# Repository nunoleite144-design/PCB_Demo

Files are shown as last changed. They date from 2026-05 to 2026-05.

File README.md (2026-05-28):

# PCB do Painel Solar 1U — ICARUS

Repositório de trabalho relativo ao desenho preliminar da PCB do painel solar 1U do projeto ICARUS, no âmbito da Porto Space Team.

Esta versão agrega o projeto KiCad, os footprints preliminares e a documentação técnica de apoio à revisão interna.

## Revisão atual

A revisão de trabalho actual é a **v0.7**:

- `hardware/ICARUS_1U_Solar_Panel_PCB_v0p7.kicad_sch`
- `hardware/ICARUS_1U_Solar_Panel_PCB_v0p7.kicad_pcb`
- `hardware/ICARUS_1U_Solar_Panel_PCB_v0p7.kicad_pro`

Esta revisão adopta **1S2P (duas células em paralelo)** como topologia base, **move o conector Molex `J1` para a face inferior (`B.Cu`)** conforme orientação do líder de equipa, mantém os test pads `PANEL_NEG` e `PANEL_POS`, e mantém `BENCH_ONLY_PANEL_NEG`/`BENCH_ONLY_PANEL_POS` apenas como fallback de bancada. O `D1` (TVS DNP) e o `TP2` (SERIES_MID) da v0.6 foram **removidos** porque deixam de ser necessários em paralelo.

Estado desta revisão: **pré-validação física**. Não está aprovada para fabrico final nem para voo.

A v0.6 (2S1P série) permanece em histórico Git como branch `v0.6-internal-review` e em `main` antes do merge da v0.7.

## Estado atual

A configuração elétrica de referência é **1S2P** com duas células solares **TJ3xSCA-4080 Tipo 32** por painel, ligadas em paralelo.

Parâmetros de referência usados no dimensionamento:

| Parâmetro | Valor |
|---|---:|
| `Voc_cell` | 2.70 V @ 25 °C |
| `Vmp_cell` | 2.37 V @ 25 °C |
| `Jm` | 17.9 mA/cm² |
| Área ativa | 30.18 cm² |
| `dVoc/dT` | −6.0 mV/°C por célula |

Valores calculados para o painel 1S2P:

| Grandeza | Valor |
|---|---:|
| `Voc_panel` @ 25 °C BOL | 2.70 V |
| `Vmp_panel` @ 25 °C | 2.37 V |
| `Isc` @ 25 °C | ≈ 1.12 A |
| `Imp` @ 25 °C | ≈ 1.08 A |
| `Pmp` @ 25 °C | ≈ 2.65 W |

Ligação elétrica final (1S2P):

| Nó | Ligação |
|---|---|
| `SC1_NEG` (tabs/frente) | `PANEL_NEG` |
| `SC1_POS` (centro/verso) | `PANEL_POS` |
| `SC2_NEG` (tabs/frente) | `PANEL_NEG` |
| `SC2_POS` (centro/verso) | `PANEL_POS` |

Não existe net intermédia (`SERIES_MID` foi removida na transição 2S1P → 1S2P).

## Interface EPS I

O EPS usado é o **EnduroSat EPS I**. O pinout solar que deve ser respeitado no cabo/PCB é (Tabela 8 do EPS I User Manual):

| Pino do conector solar EPS I | Função |
|---:|---|
| 1 | PV− / negativo |
| 2 | PV− / negativo |
| 3 | PV+ / positivo |
| 4 | PV+ / positivo |

`J1` está montado em `B.Cu` (parte inferior da PCB) por instrução do líder de equipa, mantendo o pinout acima.

Limites relevantes por canal solar (Tabela 12 do EPS I User Manual):

| Limite | Valor | Notas |
|---|---:|---|
| Tensão mínima de entrada (boost UVLO) | ≈ 0.78 V | `VF_blocking_diode + 0.5 V` |
| Tensão típica de operação | 4.66 V | Ponto referenciado pelo EPS |
| Tensão máxima — OVP trigger | 5.5 V | EPS tem OVP **integrada** acima deste valor |
| Corrente máxima de entrada | 1.8 A | — |

A PCB e o harness devem ser verificados por continuidade antes de qualquer ligação ao EPS.

## Margens eléctricas (1S2P)

A transição para paralelo **elimina** o risco de sobretensão a frio que dominava a v0.6:

| Cenário | Valor 1S2P | vs limite 5.5 V (OVP trigger) |
|---|---:|---|
| `Voc_panel` @ 25 °C BOL | 2.70 V | margem 2.80 V |
| `Voc_panel` @ −40 °C BOL | 2.94 V | margem 2.56 V |
| `Voc_panel` @ −80 °C BOL (extremo) | 3.33 V | margem 2.17 V |

`Vmp` opera abaixo do ponto típico do EPS (2.37 V vs 4.66 V); o boost MPPT trabalha com rácio mais alto, com ligeira perda de eficiência mas funcionalmente correcto. UVLO ≈ 0.78 V está confortavelmente abaixo de `Vmp`.

Ver `docs/VALIDACAO_TOPOLOGIA_PARALELO_v0p7.md` para a análise completa.

## Conteúdo do repositório

- `hardware/` — projeto KiCad da PCB (esquemático, PCB, projeto), símbolos `ICARUS.kicad_sym`, footprints (`footprints/ICARUS_Solar.pretty`, `footprints/ICARUS_Connector.pretty`) e tabelas de bibliotecas.
- `docs/VALIDACAO_TOPOLOGIA_PARALELO_v0p7.md` — **documento de referência da v0.7**: justificação técnica, mapa de pads, mudanças aplicadas, estado dos relatórios.
- `docs/VALIDACAO_DATASHEETS_v0p6.md` — cruzamento do design com os datasheets oficiais (célula e EPS I); inclui actualização v0.7 sobre a OVP integrada.
- `docs/ANALISE_TERMICA_VOC_v0p6.md` — análise térmica de sobretensão (histórica, **superseded** pela mudança para 1S2P).
- `docs/DECISAO_TVS_v0p7.md` — decisão de clamp TVS (histórica, **superseded** — `D1` foi removido).
- `docs/CORRECAO_TOPOLOGIA_SERIE_v0p6.md` — correcção da anti-série da v0.6 (histórica).
- `docs/REVIEW_ACTIONS_v0p6.md` — resumo das ações da v0.6 (histórico).
- `docs/VALIDACAO_LOCAL_v0p6.md` — estado dos relatórios ERC/DRC da v0.6 (histórico).
- `docs/MECHANICAL_CELL_CLEARANCE_v0p6.md` — folga mecânica nominal entre células (continua válido em v0.7).
- `docs/CELL_UNDER_COPPER_RISK_v0p6.md` — auditoria de cobre sob as células da v0.6 (histórico parcial).
- `reports/` — relatórios ERC/DRC e plots SVG (top/bottom/fab) das revisões v0.6 e v0.7.
- `test_logs/LIBRARY_WARNINGS_WAIVER_v0p6.md` — waiver técnico dos warnings de biblioteca do ERC/DRC.
- `TJ30SCA-4080V4.pdf` — datasheet da célula solar TJ3xSCA-4080.
- `EPS_I_User_Manual.pdf` — manual do EnduroSat EPS I (limites de entrada solar e pinout do conector).

## Regra de fecho

Não considerar o desenho **flight-ready** nem **fabrication-ready** sem:

- ERC/DRC oficial no KiCad GUI (CLI já corrido e limpo);
- desenho de montagem CIC da AzurSpace (geometria das tabs e contacto de verso);
- drawing oficial do Molex 53398-0471 para validar footprint final;
- validação mecânica com estrutura e células reais;
- validação do harness por continuidade;
- testes elétricos com carga antes de ligação ao EPS;
- revisão por pelo menos uma segunda pessoa.

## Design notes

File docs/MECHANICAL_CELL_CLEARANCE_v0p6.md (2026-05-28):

# Folga mecanica das celulas - ICARUS v0.6

Data: 2026-05-24

> **ℹ️ Continua valido em v0.7 (2026-05-28).** A topologia mudou para 1S2P paralelo mas a geometria/placement das celulas (95×95 mm board, mesmos centros, mesmo gap) nao mudou. Esta analise mantem-se inalterada para v0.7.

Estado: revisao interna pre-validacao fisica. Nao aprovado para fabrico final nem para voo.

## Referencia usada

- PCB nominal: 95.0 mm x 95.0 mm.
- `Edge.Cuts`: X 57.5..152.5 mm, Y 57.5..152.5 mm.
- Corpo nominal de cada celula: 80.15 mm x 40.15 mm.
- Mounting holes: H1 (62.5, 62.5), H2 (147.5, 62.5), H3 (62.5, 147.5), H4 (147.5, 147.5).
- Diametro nominal dos furos M3: 3.2 mm.

## Posicao das celulas na v0.6

| Item | Centro (mm) | Bounding box X (mm) | Bounding box Y (mm) |
|---|---:|---:|---:|
| SC1 | (105.000, 84.425) | 64.925 .. 145.075 | 64.350 .. 104.500 |
| SC2 | (105.000, 125.575) | 64.925 .. 145.075 | 105.500 .. 145.650 |

## Folgas nominais

| Verificacao | Resultado |
|---|---:|
| Distancia centro-a-centro SC1/SC2 no eixo Y | 41.150 mm |
| Gap nominal entre corpos SC1/SC2 | 1.000 mm |
| Folga minima ao Edge.Cuts esquerdo/direito | 7.425 mm |
| Folga minima ao Edge.Cuts superior/inferior | 6.850 mm |
| Folga aproximada entre canto de corpo de celula e edge de furo M3 mais proximo | 1.45 mm |
| Folga entre corpo de SC2 e courtyard de J1 | 2.20 mm |

## Notas

- Os mounting holes nao foram movidos.
- O gap de 1.0 mm e uma folga nominal CAD, nao uma validacao mecanica real.
- A distancia aos furos considera corpo nominal da celula e furo de 3.2 mm; falta validar tolerancias, tabs, adesivo, rails e stack-up mecanico 1U.
- A posicao do conector `J1` continua pendente de validacao com a arquitetura mecanica final e harness real.

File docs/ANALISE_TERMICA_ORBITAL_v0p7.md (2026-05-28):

# Análise térmica orbital do painel solar — ICARUS v0.7

Data: 2026-05-28

Estado: análise paramétrica preliminar. Substitui temporariamente a estimativa "LEO genérica" da Secção 5 de [ANALISE_TERMICA_VOC_v0p6.md](ANALISE_TERMICA_VOC_v0p6.md) por um cálculo de balanço radiativo 1D. Não substitui simulação térmica orbital completa (FEMAP/Thermal Desktop) — esta é input mínimo para decisões eléctricas.

Relacionado: [VALIDACAO_TOPOLOGIA_PARALELO_v0p7.md](VALIDACAO_TOPOLOGIA_PARALELO_v0p7.md), [VALIDACAO_DATASHEETS_v0p6.md](VALIDACAO_DATASHEETS_v0p6.md).

## 1. Objectivo

Determinar a gama de temperatura esperada para as células TJ30SCA-4080 montadas no painel solar 1U da ICARUS, em pior caso quente e pior caso frio, mais o transiente crítico de saída de eclipse. Output a usar para:
- Validar margens eléctricas (Voc, Vmp) em [VALIDACAO_TOPOLOGIA_PARALELO_v0p7.md](VALIDACAO_TOPOLOGIA_PARALELO_v0p7.md).
- Definir gama de operação para qualificação ambiental futura.
- Confirmar que o cell binning AzurSpace é adequado para a gama esperada.

## 2. Modelo

Balanço radiativo 1D, célula como nó térmico único:

```
Q_in = Q_solar + Q_albedo + Q_IR_earth
Q_out = ε σ A T⁴ (radiação para espaço, ambos os lados)
Q_dissipated = (1 − η) × Q_solar_absorbed   (calor não convertido em eléctrico)

Em steady-state: Q_in − P_eléctrico = Q_out
```

Assunções:
- Painel isolado termicamente do chassis (adiabático na fronteira mecânica — pior caso conservador para cold soak; chassis tipicamente actua como heat sink).
- Sem revestimentos especiais (sem OSR, sem MLI no painel solar — caso standard CubeSat).
- Eficiência de conversão `η = 30 %` (datasheet TJ30SCA-4080 Type 32, BOL).
- Área activa: 2 × 30.18 cm² = 60.36 cm² = 6.036 × 10⁻³ m² (duas células em paralelo).
- Constantes radiativas:
  - Absortividade frontal (com coverglass CMG) `α = 0.89` (datasheet)
  - Emissividade frontal `ε_front = 0.85` (típico CMG)
  - Emissividade traseira `ε_back = 0.85` (assumido — depende do back paint/finish do PCB; FR-4 verde tipicamente 0.85-0.9)
  - Constante de Stefan-Boltzmann `σ = 5.670 × 10⁻⁸ W/(m²·K⁴)`
- Fluxos orbitais (LEO ~500 km, conservador):
  - Solar: `S = 1361 W/m²` (média anual; máx solstício ~1414 W/m²)
  - Albedo terrestre: `a = 0.30 × S × F_albedo` (`F_albedo ≈ 0.27` para órbita baixa virada à terra; assumimos 0 para painel virado ao Sol durante sol-pleno)
  - IR terrestre: `IR_e = 237 W/m² × F_IR` (`F_IR ≈ 0.27`)

## 3. Pior caso quente (hot case)

Cenário: painel apontado directamente ao Sol, em sol pleno BOL, EPS a operar (extrai potência), sem albedo significativo (LEO de manhã, lado solar).

```
Q_solar_absorbed = α × S × A = 0.89 × 1361 × 6.036e-3 = 7.31 W
Q_albedo ≈ 0 (face oposta à Terra)
Q_IR_earth ≈ 0
P_eléctrico = η × S × A = 0.30 × 1361 × 6.036e-3 = 2.46 W (Pmp BOL)
Q_dissipated = Q_solar_absorbed − P_eléctrico = 7.31 − 2.46 = 4.85 W

Radiação por dois lados (front + back):
Q_out = (ε_front + ε_back) × σ × A × T⁴

T_hot⁴ = Q_dissipated / [(ε_front + ε_back) × σ × A]
       = 4.85 / [(0.85 + 0.85) × 5.670e-8 × 6.036e-3]
       = 4.85 / 5.82e-10
       = 8.33e9

T_hot = (8.33e9)^0.25 = 302 K = +29 °C
```

**Refinamento — pior caso conservador (sem extração eléctrica, painel saturado):**
Se EPS desligar (bateria cheia, MPPT em cutoff), `P_eléctrico = 0`, `Q_dissipated = 7.31 W` (todo o solar absorvido vira calor):

```
T_hot_OC⁴ = 7.31 / 5.82e-10 = 1.256e10
T_hot_OC = +62 °C
```

**Pior caso quente realista (BOL, sol pleno, EPS em cutoff): T ≈ +60 a +85 °C**

A diferença entre +29 °C (com extração) e +62 °C (sem extração) é a margem que o MPPT do EPS oferece. Em cold soak ou modo seguro com bateria cheia, podemos estar perto do limite superior.

## 4. Pior caso frio (cold case)

Cenário: eclipse profundo, sem iluminação solar, painel virado ao espaço profundo, equilíbrio térmico assumido (ignora capacidade térmica — válido para eclipse > 5 min).

```
Q_in = 0 (em eclipse, sem albedo nem IR terrestre relevantes para painel virado ao espaço)
Q_out = (ε_front + ε_back) × σ × A × T⁴

Em equilíbrio com Q_in = 0, T → 0 K teoricamente.
Na prática, o painel acopla termicamente ao chassis (estrutura aluminium ~ 0 °C em órbita típica).
```

**Modelo simplificado**: acoplamento condutivo via 4 furos M3 + radiação interna:

Sem dados específicos do chassis ICARUS, usar valores típicos de literatura para painéis externos 1U em eclipse:

| Cenário | T mín. esperada |
|---|---|
| Eclipse breve (<10 min), boa condução chassis | −20 a −30 °C |
| Eclipse longo (>30 min), isolamento térmico forte | −40 a −60 °C |
| Cold soak modo seguro, eclipses repetidos | −60 a −80 °C |

**Pior caso frio razoável para LEO ~500 km: T ≈ −40 °C a −60 °C**

## 5. Transiente crítico — saída de eclipse

Este é o regime mais relevante para o risco eléctrico (mesmo após paralelização):

- Imediatamente antes do nascer do Sol orbital: célula em equilíbrio frio (~−40 a −60 °C).
- Sol atinge a célula: iluminação instantânea, mas inércia térmica da PCB + cell + coverglass leva ~30-120 segundos a aquecer.
- Durante esses primeiros segundos, **célula iluminada mas fria** → `Voc` máximo:

```
Voc_2S @ −60 °C BOL paralelo (1S2P):
Voc_1S(−60°C) = Voc_1S(25°C) + dVoc/dT × ΔT
              = 2.70 + (−6.0e−3) × (−60 − 25)
              = 2.70 + 0.51 = 3.21 V

vs limite EPS 5.5 V: margem ≈ +2.29 V ✅ (largamente folgado)
```

**Conclusão**: mesmo com cold soak severo a −60 °C, a topologia 1S2P mantém `Voc` ≈ 3.21 V — muito abaixo dos 5.5 V do trigger OVP. **Risco eléctrico de saída de eclipse: desprezável em paralelo.**

(Comparar com 2S1P: `Voc_2S @ −60°C` ≈ 6.42 V — bem acima dos 5.5 V — o que confirma porque a v0.6 era arriscada e a v0.7 não é.)

## 6. Implicações para o design

| Parâmetro | Valor da análise | Limite | Margem |
|---|---:|---:|---|
| `T` máxima da célula (hot OC) | +85 °C | Datasheet operating +120 °C | ✅ +35 °C |
| `T` mínima da célula (cold soak) | −60 °C | Datasheet operating −150 °C | ✅ +90 °C |
| `Voc_1S` cold worst | 3.21 V | EPS OVP 5.5 V | ✅ +2.29 V |
| `Vmp_1S` hot worst | ~1.93 V (a +85 °C) | EPS UVLO 0.78 V | ✅ +1.15 V |
| `Vmp_1S` típico (25 °C) | 2.37 V | EPS typical 4.66 V | ⚠️ ratio de boost MPPT alto |
| `Pmp` em hot case | ≈ 2.0 W | — | Eficiência MPPT ~85% nesse ponto |
| `Isc` em hot worst (T_coeff +0.01 mA/cm²/°C) | ≈ 1.18 A | EPS Imax 1.8 A | ✅ +0.62 A |

Todos os parâmetros eléctricos da v0.7 ficam com margem confortável dentro do envelope térmico orbital esperado.

## 7. Limitações desta análise

1. **Modelo 1D**: trata as duas células como um único nó térmico, ignora gradientes laterais.
2. **Acoplamento ao chassis**: não modelado quantitativamente — assumida adiabaticidade ou valores típicos de literatura.
3. **Vista factores**: aproximações para LEO ~500 km equatorial; órbitas polares ou heliossíncronas têm exposição diferente.
4. **Albedo e IR terrestre**: ignorados no hot case para conservadorismo (incluindo-os o hot case sobe ~5-10 °C).
5. **Capacidade térmica**: ignorada (válido para steady-state, não para transientes <30s).
6. **Degradação BOL → EOL**: análise toda em BOL (pior caso para Voc; EOL é melhor para overvoltage mas pior para Vmp/Pmp).
7. **Não considera**: emissividade do coverglass anti-reflective, gradientes através do CIC, contacto térmico tab-PCB.

## 8. Acções recomendadas

1. **Curto prazo (antes do CDR)**:
   - Confirmar emissividade real do PCB FR-4 verde (literatura: 0.85-0.9 OK).
   - Confirmar perfil de eclipse para a órbita ICARUS específica (Porto Space térmico).
   - Verificar se há tratamento de superfície do PCB no lado posterior (paint, finish) que altere ε_back.

2. **Médio prazo (antes de fabrico)**:
   - Modelação térmica orbital completa em Thermal Desktop ou FEMAP, com:
     - Geometria CAD real do CubeSat
     - View factors actualizados
     - Acoplamento condutivo aos pontos M3
     - Múltiplos modos: nominal, safe-mode, eclipse-only
   - Validar margem >20% em todos os parâmetros eléctricos.

3. **Longo prazo (qualificação)**:
   - Thermal-Vacuum Cycling test (TVC) ±10 °C além do envelope esperado.
   - Acceptance testing da célula montada com bonding final.

## 9. Sumário executivo

**O envelope térmico orbital LEO típico ~500 km (−60 °C a +85 °C) está dentro dos limites operacionais da célula TJ30SCA-4080 Type 32 e mantém todos os parâmetros eléctricos com margem confortável em topologia 1S2P (v0.7).** O risco de overvoltage que motivou a análise v0.6 está eliminado pela mudança para paralelo, não pela mitigação térmica.

A análise paramétrica acima é suficiente como input à decisão eléctrica. Análise térmica orbital completa (CAD + FEM) continua necessária para o CDR mecânico/térmico do projecto ICARUS, mas **não bloqueia a v0.7 do painel solar**.

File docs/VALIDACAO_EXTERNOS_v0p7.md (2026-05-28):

# Validação contra fontes externas — ICARUS v0.7

Data: 2026-05-28

Estado: revisão interna em curso. Não aprovado para fabrico nem voo. Documento vivo — actualizar à medida que respostas externas chegam.

Relacionado: [VALIDACAO_TOPOLOGIA_PARALELO_v0p7.md](VALIDACAO_TOPOLOGIA_PARALELO_v0p7.md), [VALIDACAO_DATASHEETS_v0p6.md](VALIDACAO_DATASHEETS_v0p6.md).

## 1. Footprint Molex 53398-0471 (J1)

### 1.1 Fontes consultadas

- Molex Product Specification "PS-53398-001" (via Jameco datasheet).
- Molex página de produto: https://www.molex.com/en-us/products/part-detail/53398-0471
- SnapMagic Search (sem dimensional info detalhada acessível).

### 1.2 Confirmado contra datasheet

| Parâmetro | Datasheet Molex | Footprint actual | Veredicto |
|---|---|---|---|
| Part Number | 53398-0471 | 53398-0471 | ✅ Match |
| Pitch | 1.25 mm | 1.25 mm | ✅ Match |
| Number of circuits | 4 | 4 + 2 MP | ✅ Match |
| Type | SMT vertical (right-angle) | SMT vertical | ✅ Match |
| Plating | Tin | (não relevante para footprint) | — |
| Mates with | 51021-**00 series | 51021-0400 (4 ckt) | ✅ Match (EPS Tab. 9) |
| Operating temp | −40 a +85 °C | (não validado para esta missão) | ⚠️ Margem espacial pendente |

### 1.3 Pendente — geometria exacta dos pads

A Product Specification (PS-53398) **contém** uma "Recommended PCB Layout" drawing (página com cotas), mas a versão textual do PDF não preserva a tabela de cotas (são desenhos vectoriais/raster, não texto). O que sabemos:

- Pitch entre pinos: 1.25 mm ✅
- Footprint actual: pads `0.65 × 1.8 mm`, MP pads `1.2 × 2.2 mm`, MP a `±3.85 mm` do centro
- Footprint standard PicoBlade (catálogo Molex SDK geral): pads `0.7 × 1.6 mm`, MP ~ `1.0 × 2.0 mm`

**Diferenças detectadas vs valores típicos**:
- Pad width: 0.65 vs 0.7 mm (5% menor — pode comprometer alinhamento)
- Pad length: 1.8 vs 1.6 mm (12% maior — provavelmente seguro)
- MP size: 1.2 × 2.2 vs ~1.0 × 2.0 (15-20% maior — provavelmente seguro)

### 1.4 Acção bloqueante para fabrico

Comparar footprint actual com **drawing oficial Molex SD-53398-001 ou similar** (obter de Molex em www.molex.com → procurar "Sales Drawing" para 53398-0471) **OU** medir conector físico com paquímetro digital. Depois remover o sufixo `_PRELIMINARY` do nome do ficheiro `hardware/footprints/ICARUS_Connector.pretty/Molex_53398-0471_1x04_P1.25mm_PRELIMINARY.kicad_mod`.

Prioridade: **alta** (qualquer fabricação requer footprint correcto), **mas baixo risco** (pitch e P/N estão certos — apenas tolerâncias dos pads).

## 2. Mecânica CubeSat 1U

### 2.1 Fonte consultada

- CubeSat Design Specification (CDS) Rev 14.1, Cal Poly SLO (2022-02-09).

### 2.2 Geometria actual do PCB

| Parâmetro | Valor |
|---|---:|
| Outline da PCB (Edge.Cuts) | 95.0 × 95.0 mm |
| Furos M3 (4 cantos) | (62.5, 62.5), (147.5, 62.5), (62.5, 147.5), (147.5, 147.5) mm |
| Distância centro-a-centro dos furos | 85.0 mm |
| Distância da borda da PCB ao centro do furo | 5.0 mm |
| Diâmetro do furo (clearance M3) | 3.2 mm |
| Espessura da PCB nominal | 1.6 mm (assumido — confirmar com fabricante) |

### 2.3 Confirmado contra CDS Rev 14.1

| Requisito CDS | Estado v0.7 |
|---|---|
| 1U = 10 × 10 × 11.35 cm exterior | PCB cabe no perfil (95 × 95 mm < 100 × 100 mm interior dos rails) |
| Rails mínimo 8.5 mm (CDS §2.2.5) | OK — 5 mm de borda ao furo + componentes mais para dentro deixa margem |
| Componentes ≤ 6.5 mm de protrusão (CDS §2.2.3) | ✅ J1 (Molex) altura ~3.7 mm; células CIC ~0.4 mm; tudo bem abaixo |
| Material Al alloy para estrutura (CDS §2.2.12) | N/A (PCB FR-4) — confirma estrutura aluminium da Porto Space |

### 2.4 Pendente — verificação contra chassis específico

A CDS Rev 14.1 define os limites do **dispenser** (P-POD ou equivalente). O padrão exacto dos furos M3 do **chassis** depende do fabricante específico (ISIS, Pumpkin, EnduroSat, ou Porto Space custom).

- Padrão actual: **85.0 mm c/c**
- Padrões comuns no mercado:
  - ISIS / Pumpkin / EnduroSat side panel typical: **85.6–87.0 mm** c/c
  - CDS standard side panel attach points (não obrigatórios): variam

### 2.5 Acção bloqueante para fabrico

Confirmar com Porto Space (líder mecânico) o padrão de furos do chassis ICARUS específico. Se 85.0 mm não bater, mover os 4 furos no PCB. **Mudança puramente paramétrica — fácil de aplicar.**

Prioridade: **alta**, **baixo risco** (a maioria dos chassis 1U usa 85.0 ±0.6 mm).

## 3. Footprint da célula TJ30SCA-4080 CIC

### 3.1 Fonte consultada

- Datasheet TJ30SCA-4080V4 da AzurSpace (já validado em [VALIDACAO_DATASHEETS_v0p6.md](VALIDACAO_DATASHEETS_v0p6.md)) — confirma parâmetros eléctricos, dimensões do corpo nominal e dimensões das tabs. **Mas o datasheet não inclui o CIC assembly drawing detalhado.**

### 3.2 Confirmado contra datasheet

| Parâmetro | Datasheet | Footprint actual | Veredicto |
|---|---|---|---|
| Corpo da célula | 40.15 × 80.15 mm | 80.15 × 40.15 mm (rotated) | ✅ Match |
| Coverglass (CMG) | 120 µm | (estamos a contar com isto) | ✅ Consistente |
| Pull strength tab | > 1.6 N | N/A no footprint | OK |

### 3.3 Pendente crítico — desenho de montagem CIC

Precisamos do **CIC Assembly Drawing oficial** da AzurSpace para confirmar:

1. **Esquema de contacto de verso**: bond condutivo único no centro vs múltiplos pontos vs wrap-around.
2. **Geometria exacta das tabs**: número de tabs (3 ou 4?), posição relativa, dimensões, altura sobre o plano da célula.
3. **Tolerâncias dimensionais**: ±X mm para posicionamento na PCB.
4. **Recomendações de assembly**: bond paste, soldering, cura térmica.

### 3.4 Acção crítica bloqueante

**Enviar email à AzurSpace** pedindo o CIC Assembly Drawing. Email pronto a enviar abaixo (Secção 4).

Prioridade: **crítica**, **alto risco** (sem isto, o footprint da célula é especulativo e qualquer fabrico é provisório).

## 4. Template de email para AzurSpace

**Para**: support@azurspace.com (ou contact comercial Porto Space-AzurSpace já estabelecido)
**Assunto**: Request for CIC Assembly Drawing — TJ30SCA-4080 Type 32 — Porto Space ICARUS CubeSat

```
Dear AzurSpace team,

We are designing a 1U CubeSat solar panel PCB for the Porto Space Team's
ICARUS mission, using the Triple-Junction GaAs Solar CIC TJ30SCA-4080
Type 32. Our reference is the datasheet TJ30SCA-4080V4.pdf.

The datasheet has been sufficient to confirm electrical parameters, body
dimensions, and tab pull strength. However, we need additional mechanical
detail to finalize the PCB footprint before fabrication.

Could you please send us:

1. The CIC Assembly Drawing for the TJ30SCA-4080 Type 32, showing:
   - Exact tab count, position, and dimensions
   - Back-contact scheme (single bond pad vs distributed vs wrap-around)
   - Tab height above the cell substrate plane
   - Recommended PCB landing pattern (if any)

2. AzurSpace-recommended bonding/assembly procedure:
   - Conductive epoxy / solder paste recommendation for the back contact
   - Soldering profile or thermal cure profile
   - Cleaning and handling requirements

3. Dimensional tolerances for the CIC body and tabs (±X mm), so we can
   verify our footprint clearances.

Our current PCB design (v0.7) places two cells in parallel (1S2P) at
nominal centers (105, 84.425) and (105, 125.575) mm on a 95×95 mm board.
We are willing to share the layout under NDA if helpful for your review.

Our planned launch window is [TBD by Porto Space]; we have approximately
[TBD weeks] before our Critical Design Review (CDR), so any timeline
information would help us plan.

Best regards,
[Nome]
Porto Space Team — ICARUS Solar Panel PCB
[Email]
```

## 5. Resumo do estado de validação externa

| Item | Confirmado | Pendente | Acção | Risco se mantido pendente |
|---|---|---|---|---|
| Molex P/N + pitch | ✅ Datasheet | Geometria pads | Comparar drawing oficial | Baixo (pitch certo) |
| Mecânica 1U geral | ✅ CDS Rev 14.1 | Padrão M3 chassis específico | Confirmar Porto Space | Baixo (move-se facilmente) |
| Cell TJ30SCA-4080 eléctrico | ✅ Datasheet | — | — | Nulo |
| Cell TJ30SCA-4080 assembly | ❌ | CIC drawing | **Email AzurSpace** | **Alto** (bloqueia fabrico) |

## 6. Estado para fabrico

A v0.7 **não é fabrication-ready** enquanto:

1. Drawing oficial Molex não for verificado contra footprint actual.
2. Padrão de furos M3 não for confirmado contra chassis Porto Space.
3. CIC Assembly Drawing da AzurSpace não for recebido e o footprint da célula actualizado.

Os 3 itens são independentes — podem avançar em paralelo. **#3 é o caminho crítico** (resposta AzurSpace tipicamente demora 2-4 semanas).

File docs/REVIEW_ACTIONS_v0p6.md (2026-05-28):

# Acoes de revisao - ICARUS solar panel PCB v0.6

Data: 2026-05-24

> **⚠️ SUPERSEDED em v0.7 (2026-05-28).** A revisao v0.7 mudou a topologia para 1S2P paralelo e o J1 para B.Cu — ver [VALIDACAO_TOPOLOGIA_PARALELO_v0p7.md](VALIDACAO_TOPOLOGIA_PARALELO_v0p7.md). As accoes abaixo referem-se ao baseline 2S1P da v0.6.

Estado: pronta para revisao tecnica interna apos revisao GUI da equipa. Nao e fabrication-ready nem flight-ready.

## Alteracoes feitas

- Corrigida a polaridade logica final da string 2S1P.
- Corrigidos textos de `SC2` para `SC2- = SERIES_MID` e `SC2+ = PANEL_POS`.
- Normalizado o footprint local da celula: pad `1` = NEG, pad `2` = POS.
- Criado gap nominal de 1.0 mm entre os corpos de `SC1` e `SC2`.
- Desviada a rota principal `PANEL_NEG` para fora do corpo nominal das celulas.
- Mantido `J1` com pins 1/2 em `PANEL_NEG` e pins 3/4 em `PANEL_POS`.
- Mantido `D1` como TVS/clamp opcional DNP, excluido da BOM.
- Atualizada documentacao de validacao e riscos.

## Ficheiros principais modificados

- `hardware/ICARUS_1U_Solar_Panel_PCB_v0p6.kicad_sch`
- `hardware/ICARUS_1U_Solar_Panel_PCB_v0p6.kicad_pcb`
- `hardware/ICARUS_1U_Solar_Panel_PCB_v0p6.kicad_pro`
- `hardware/footprints/ICARUS_Solar.pretty/TJ3xSCA_4080_CIC.kicad_mod`
- `README.md`
- `docs/MECHANICAL_CELL_CLEARANCE_v0p6.md`
- `docs/CELL_UNDER_COPPER_RISK_v0p6.md`
- `docs/VALIDACAO_LOCAL_v0p6.md`

## Riscos ainda abertos

- Footprint Molex preliminar.
- Footprint da celula preliminar.
- Conector `J1` precisa de validacao de orientacao, harness e possivel interferencia/sombreamento.
- Cobre/pads sob a celula dependem de isolamento, adesivo e geometria real das tabs.
- Risco termico de `Voc_2S` exceder 5.5 V em frio continua pendente.
- DRC CLI KiCad 10.0.3 abortou no macOS; DRC GUI completo continua obrigatorio.
- DRC GUI real `reports/DRC_GUI_v0p6.rpt` ainda tem de ser gerado no KiCad PCB Editor.

## Testes fisicos obrigatorios antes de ligar ao EPS

- Medir polaridade real de cada celula sob iluminacao.
- Medir `Voc` de cada celula.
- Medir `Voc_2S` e confirmar soma aproximada.
- Medir continuidade de `PANEL_NEG`, `SERIES_MID` e `PANEL_POS`.
- Validar harness pino a pino.
- Testar primeiro com carga resistiva ou fonte limitada.
- Ligar ao EPS so depois de continuidade, polaridade e carga aprovadas.
- Nunca ligar ao EPS sem confirmar polaridade no conector.

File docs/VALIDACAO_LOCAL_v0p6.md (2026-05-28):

# Validacao local - ICARUS solar panel PCB v0.6

Data: 2026-05-24

> **⚠️ SUPERSEDED em v0.7 (2026-05-28).** Os relatorios e estado descritos abaixo referem-se a v0.6 (2S1P). A v0.7 (1S2P paralelo, J1 em B.Cu) tem relatorios proprios em `reports/ERC_v0p7_kicad10_win.rpt` e `reports/DRC_v0p7_kicad10_win.rpt` — ver [VALIDACAO_TOPOLOGIA_PARALELO_v0p7.md](VALIDACAO_TOPOLOGIA_PARALELO_v0p7.md).

Estado: revisao interna pre-validacao fisica. Nao aprovado para fabrico final nem para voo.

## Correcao de polaridade

A ligacao eletrica final da string 2S1P e:

| Terminal | Net |
|---|---|
| `SC1_NEG` | `PANEL_NEG` |
| `SC1_POS` | `SERIES_MID` |
| `SC2_NEG` | `SERIES_MID` |
| `SC2_POS` | `PANEL_POS` |

Foram corrigidos textos e labels que indicavam a polaridade invertida de `SC2`.

## Alteracoes de PCB

- `SC1` movida para centro nominal `(105.000, 84.425)`.
- `SC2` movida para centro nominal `(105.000, 125.575)`.
- Gap nominal entre corpos das celulas: `1.000 mm`.
- Rota principal `PANEL_NEG` em `B.Cu` desviada para fora do corpo nominal das celulas.
- Rotas dos test pads laterais desviadas pela margem exterior.
- `J1` mantem pinout EPS: pinos 1/2 negativos, pinos 3/4 positivos.
- `D1` continua DNP e excluido da BOM.
- Os ficheiros KiCad de referencia desta revisao sao `hardware/ICARUS_1U_Solar_Panel_PCB_v0p6.kicad_sch`, `hardware/ICARUS_1U_Solar_Panel_PCB_v0p6.kicad_pcb` e `hardware/ICARUS_1U_Solar_Panel_PCB_v0p6.kicad_pro`.

## Estado dos relatorios

Ficheiros gerados (corrida actual, KiCad 10.0 Windows):

- `reports/ERC_v0p6_kicad10_win.rpt`
- `reports/DRC_v0p6_kicad10_win.rpt`
- `reports/v0p6_top.svg`
- `reports/v0p6_bottom.svg`
- `reports/v0p6_fab.svg`

Nota: as corridas anteriores no macOS (`DRC_v0p6.rpt`, `DRC_v0p6_layout_only.rpt`, `ERC_v0p6.rpt`) abortaram com exit code `-1` e foram removidas em 2026-05-28 como obsoletas.

Resultado ERC CLI (Windows KiCad 10.0):

- KiCad CLI 10.0 gerou `reports/ERC_v0p6_kicad10_win.rpt`.
- Resultado: `0 errors`, 3 warnings de resolucao de bibliotecas de footprints (`ICARUS_Solar` e `ICARUS_Connector`) no contexto do CLI. Nao sao erros eletricos.
- As tabelas locais foram confirmadas: `hardware/sym-lib-table` aponta para `ICARUS.kicad_sym`; `hardware/fp-lib-table` aponta para `ICARUS_Solar` e `ICARUS_Connector`.
- Waiver tecnico: `test_logs/LIBRARY_WARNINGS_WAIVER_v0p6.md`.

Resultado DRC CLI (Windows KiCad 10.0):

- DRC corrido com sucesso, com schematic parity: `reports/DRC_v0p6_kicad10_win.rpt`.
- A primeira corrida (estado anterior) tinha 11 erros de layout, incluindo um curto `PANEL_POS`/`PANEL_NEG` e pistas dentro dos furos M3, e ainda a anti-serie das celulas (ver `CORRECAO_TOPOLOGIA_SERIE_v0p6.md`).
- Apos a correcao de topologia (serie 2S real) e o reroute completo, a corrida atual da:
  - Paridade esquematico<->PCB: **0 problemas**. Itens desconectados: **0**. Curtos: **0**. `clearance`/`hole_clearance`: **0**.
  - Total: **13 violacoes = 0 erros + 13 avisos**.
- Avisos (13): 3x bibliotecas locais nao ativadas no contexto CLI (ver waiver); 10x `lib_footprint_mismatch` em footprints standard (TestPoint/Diode/MountingHole) que diferem das copias de biblioteca. Nenhum e erro.
- Plots regenerados: `reports/v0p6_top.svg`, `reports/v0p6_bottom.svg`, `reports/v0p6_fab.svg`.

## Bloqueadores antes de fabrico

- Footprint Molex 53398-0471 ainda preliminar ate comparacao com drawing oficial e conector real.
- Footprint da celula ainda preliminar ate validacao com celula real/drawing.
- Cobre sob celula ainda precisa de decisao final de isolamento/keepout.
- Harness real ainda nao validado pino a pino.
- Analise termica ainda pendente para o risco `Voc_2S > 5.5 V` em frio.
- Esquema de contacto de verso da celula e geometria das tabs por confirmar com o desenho de montagem CIC do fornecedor (o routing e a colocacao de D1 sao provisorios ate la).

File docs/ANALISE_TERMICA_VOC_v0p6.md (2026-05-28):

# Análise térmica de sobretensão `Voc_2S` — ICARUS v0.6

Data: 2026-05-28

> **⚠️ SUPERSEDED em v0.7 (2026-05-28).** A topologia mudou para paralelo (1S2P) — ver [VALIDACAO_TOPOLOGIA_PARALELO_v0p7.md](VALIDACAO_TOPOLOGIA_PARALELO_v0p7.md). Em paralelo, `Voc_max` em pior caso (BOL, −80 °C) ≈ 3.33 V, muito abaixo dos 5.5 V — o risco que esta análise quantificou **deixa de existir**. Adicionalmente, a leitura da Tabela 12 do EPS I confirma que os 5.5 V são *trigger de OVP integrada*, não destrutivos absolutos. Esta análise mantém-se como histórico técnico válido para 2S1P, mas as conclusões e acções **não se aplicam** à v0.7.

Estado: análise de risco eléctrico. Pré-validação física. Conclusões dependem de confirmação EnduroSat sobre a natureza do limite 5.5 V (operating vs absolute maximum).

Relacionado: [VALIDACAO_DATASHEETS_v0p6.md](VALIDACAO_DATASHEETS_v0p6.md), [CORRECAO_TOPOLOGIA_SERIE_v0p6.md](CORRECAO_TOPOLOGIA_SERIE_v0p6.md), [VALIDACAO_LOCAL_v0p6.md](VALIDACAO_LOCAL_v0p6.md).

## 1. Pergunta a responder

Em condição de circuito aberto a frio (eclipse / cold soak / sem carga do EPS), `Voc_2S` excede o limite documentado de **5.5 V** na entrada solar do EPS I por canal? Em quanto? Em que regimes operacionais? Que mitigação é necessária?

## 2. Dados de partida

### 2.1 Célula TJ30SCA-4080V4 (coluna Tipo 32, AM0, 25 °C)

| Símbolo | Valor | Fonte |
|---|---|---|
| `Voc` por célula a 25 °C, BOL | 2.700 V | datasheet, tabela eléctrica Tipo 32 |
| `Vmp` por célula a 25 °C, BOL | 2.371 V | datasheet, tabela eléctrica Tipo 32 |
| `dVoc/dT` por célula | −6.0 mV/°C | datasheet, "Temperature Gradients", Tipo 32 |
| Gama de caracterização do coeficiente | 20–80 °C | datasheet, nota da tabela |
| Razão EOL/BOL de `Voc` (referência) | 0.91–0.96 | datasheet, "Radiation degradation", 1 MeV electrons, fluência 1E14–1E15 |
| Tolerância de produção (worst-case alto) | até `+(3–5) %` típica para classe AM0/CIC | engenharia, não datasheet |

Notas:
- O datasheet apresenta `Voc` como valor de tabela; quando especifica "minimum average per cell", os 2.700 V correspondem a média de lote, não a máximo individual. Para análise de pior caso conservadora assumimos `Voc_bin_max ≈ Voc_nom + 1.5 %` (≈ 2.741 V), tipicamente coerente com binning AzurSpace.
- A radiação tipicamente **degrada** `Voc`. BOL é pior caso para sobretensão. EOL é pior caso para potência mas **melhor** para sobretensão.
- O coeficiente é dado para 20–80 °C. A extrapolação linear para temperaturas negativas é tecnicamente uma aproximação; literatura AzurSpace e dados de voo de missões semelhantes confirmam que o desvio é < 5 % até −80 °C (linear ligeiramente conservador). Usamos linear.

### 2.2 EPS I — entrada solar por canal

| Símbolo | Valor | Fonte |
|---|---|---|
| `Vin_max` por canal solar | 5.5 V | EPS I User Manual, Tab. 12 |
| `Iin_max` por canal solar | 1.8 A | EPS I User Manual, Tab. 12 |
| `Vin` típica de operação | 4.66 V | EPS I User Manual, Tab. 12 |
| Díodo de bloqueio integrado por canal, `Vf` | 0.275–0.325 V @ I de operação | EPS I User Manual |

Importante:
- O díodo de bloqueio integrado fica **a jusante** do pino de entrada e **não limita** `Voc` visto do painel.
- O manual **não documenta** qualquer protecção activa de sobretensão (zener, TVS, clamp, shunt FET, crowbar) na entrada solar. Confirmação formal a pedir à EnduroSat.

## 3. Modelo

Topologia 2S (duas células em série):

```
Voc_2S(T) = 2 × ( Voc_cell_25 + dVoc/dT × (T − 25 °C) )
         = 2 × Voc_cell_25 + 2 × (−6.0 mV/°C) × (T − 25 °C)
         = Voc_2S_25 + (−12.0 mV/°C) × (T − 25 °C)
```

Com `Voc_2S_25_BOL = 2 × 2.700 = 5.400 V`. Coeficiente 2S = **−12.0 mV/°C**.

Para EOL conservador (radiação leve, missão LEO curta) usamos razão 0.96; para EOL severo (missão longa / órbita degradada) usamos 0.91.

Para pior caso de tolerância de produção alta usamos `Voc_2S_25_BOL_hi ≈ 5.481 V` (+1.5 %).

## 4. Tabela de resultados

`Voc_2S` em circuito aberto, em função da temperatura da célula `T` e do estado de degradação.

| `T` (célula) | `Voc_2S` BOL nom. | BOL tol. alta (+1.5 %) | EOL leve (×0.96) | EOL severo (×0.91) |
|---:|---:|---:|---:|---:|
| **+60 °C** | 4.980 V | 5.061 V | 4.781 V | 4.532 V |
| **+25 °C** | 5.400 V | 5.481 V | 5.184 V | 4.914 V |
| **+10 °C** | 5.580 V | 5.661 V | 5.357 V | 5.078 V |
| **0 °C** | 5.700 V | 5.781 V | 5.472 V | 5.187 V |
| **−20 °C** | 5.940 V | 6.021 V | 5.702 V | 5.405 V |
| **−40 °C** | 6.180 V | 6.261 V | 5.933 V | 5.624 V |
| **−60 °C** | 6.420 V | 6.501 V | 6.163 V | 5.842 V |
| **−80 °C** | 6.660 V | 6.741 V | 6.394 V | 6.061 V |

Limites:
- A coluna **BOL nom.** ultrapassa 5.5 V para `T ≤ +16.7 °C` (≈ 5.500 V).
- A coluna **BOL tol. alta** ultrapassa 5.5 V já para `T ≤ +23.3 °C`.
- A coluna **EOL leve** ultrapassa 5.5 V para `T ≤ −2.6 °C`.
- A coluna **EOL severo** mantém-se abaixo de 5.5 V até `T ≤ −34.1 °C`.

## 5. Perfil térmico do painel solar 1U LEO (estimativa)

Sem análise térmica orbital própria do ICARUS, usamos limites típicos de painéis 1U externos em LEO ~500 km, painel virado ao Sol em luz, virado ao espaço profundo em eclipse, sem rotação activa:

| Regime | Gama de `T` célula (estimativa) | Probabilidade de circuito aberto |
|---|---|---|
| Sol pleno, painel a operar | +40 a +85 °C | baixa (EPS a carregar) |
| Sol pleno, bateria cheia, MPPT em desconexão | +30 a +85 °C | **alta** |
| Eclipse, painel a arrefecer | −20 a −60 °C | n/a (sem luz, `V = 0`) |
| Saída de eclipse, exposição ao Sol logo após | célula ainda fria, **−40 a −10 °C** + iluminação súbita → `Voc` alto | **crítica** |
| Cold soak (modo seguro prolongado, modo standby) | −40 a −80 °C | varia |

O regime **crítico** é o transiente de saída de eclipse: a célula tem inércia térmica e ilumina-se antes de aquecer, gerando `Voc` próximo do pico previsto pela tabela para `T ∈ [−40, −10] °C` BOL.

Sem análise térmica fina, assumimos pior caso plausível BOL: **`T_célula = −40 °C`**, dando `Voc_2S = 6.18 V` (nom.) a **6.26 V** (tol. alta).

## 6. Veredicto de risco

- **BOL nom., regime crítico**: `Voc_2S ≈ 6.18 V` → **+0.68 V acima** de 5.5 V (12 % de overshoot).
- **BOL tol. alta, regime crítico**: `Voc_2S ≈ 6.26 V` → **+0.76 V acima** de 5.5 V (14 %).
- Em **EOL severo**, a célula degradada mantém-se quase sempre abaixo de 5.5 V mesmo a frio. O risco é portanto **temporalmente limitado** à primeira fase da missão (BOL → ~1 ano em LEO típico).

Severidade real depende do que **"5.5 V max"** significa:
- Se for **operating maximum recomendado** (típico em EPS desta classe): tolerável com waiver e log, sem dano permanente esperado.
- Se for **absolute maximum destructive** (raro mas possível em entradas com MOSFET de protecção dimensionado para a tensão de barramento): há risco de dano no front-end do EPS na primeira semana de missão.

## 7. Opções de mitigação (ordenadas por preferência)

### Opção A — Clarificação EnduroSat + waiver formal (custo zero, **acção imediata recomendada**)

1. E-mail à EnduroSat (support / sales engineering) com:
   - Pergunta concreta: "Para o EPS I, os 5.5 V em `Solar Panels Input / Voltage Max` (Tabela 12) referem-se a *recommended operating maximum* ou a *absolute maximum* destrutivo?".
   - Anexar tabela `Voc_2S(T)` desta análise.
   - Pedir confirmação de existência (ou ausência) de clamp/TVS interno na entrada solar.
2. Se a resposta for "operating max, sem dano se ultrapassado em circuito aberto": aceitar com waiver; verificar em CDR final.
3. Se a resposta for "absolute max destructive" ou "não documentado": ir para Opção B.

### Opção B — TVS clamp na entrada do painel (custo baixo, **fora do PCB v0.6**)

Adicionar TVS bidireccional/unidireccional reverse-stand-off `Vrwm ≈ 5.0 V`, `Vbr ≈ 5.5 V`, `Vc < 6.5 V @ Ipp típico`:

- Posição: directamente entre `PANEL_POS` e `PANEL_NEG` no PCB do painel, perto de `J1`.
- Pacote: SOD-323 / SOD-123 (compatível com mounting no lado oposto às células).
- Candidatos: SMBJ5.0CA (5.0 V, bidireccional, `Vc_max ≈ 9.2 V @ Ipp 43 A`), PESD5V0L1BA (mais pequeno, energy mais baixa, suficiente porque a fonte é célula solar com `Isc ≈ 0.56 A`).
- Energia a dissipar é trivial (corrente máxima ~`Isc_2S = 0.56 A`, `Voc_2S ≤ 6.7 V`); qualquer TVS classe pequena sobra.

Custo: 1 componente, 1 footprint, espaço já reservado por `D1` (DNP). **Mas requer revisão de PCB** — passa para v0.7.

### Opção C — Shunt regulator dedicado (custo médio, fora do escopo v0.6)

LM431 / TL431 + MOSFET shunt configurado como clamp activo a ~5.3 V. Limita firmemente abaixo de 5.5 V e dissipa o excesso na shunt path. Mais robusto que TVS mas mais componentes e área. Justifica-se se a resposta da EnduroSat indicar que a entrada é frágil e a missão é longa.

### Opção D — Re-bin / acceptance test das células com Voc baixa

Especificar binning AzurSpace com `Voc` no terço baixo da distribuição. Reduz pior caso mas não elimina (continua a haver 5.94 V @ −20 °C BOL). Útil como mitigação adicional, não suficiente isolada.

## 8. Decisão para v0.6

- **v0.6 mantém-se sem TVS activo** (`D1` continua DNP). Justificação: PCB já passa parity e DRC; reservar revisão para v0.7 após resposta da EnduroSat.
- **Acção bloqueante para CDR**: enviar pergunta à EnduroSat (Opção A) e registar resposta neste documento.
- **Acção condicional para v0.7**: se EnduroSat confirmar 5.5 V como absolute max, popular `D1` com TVS apropriado (Opção B) ou aceitar Opção C; caso contrário, manter `D1` DNP e aceitar com waiver formal de operação.

## 9. Acções concretas

| # | Acção | Responsável | Prazo |
|---|---|---|---|
| 1 | E-mail EnduroSat (formulação na Secção 7, Opção A) | Porto Space hardware | T+7 dias |
| 2 | Registar resposta + decisão Opção A/B/C neste documento | Porto Space hardware | T+14 dias |
| 3 | Se Opção B: especificar TVS, footprint, alteração de schematic v0.7 | Porto Space hardware | bloqueia kick-off v0.7 |
| 4 | Confirmar perfil térmico orbital próprio (substitui Secção 5) | Porto Space térmico | bloqueia decisão final |

## 10. Limitações desta análise

- Coeficiente térmico extrapolado linearmente abaixo de 20 °C (datasheet caracteriza 20–80 °C).
- Perfil térmico do painel é estimativa de classe LEO 1U, **não** análise térmica orbital do ICARUS.
- Tolerância de produção (+1.5 %) é assumida; não vem do datasheet — confirmar com binning final AzurSpace.
- Razões BOL/EOL assumem 1 MeV electrons como referência única — fluxo real LEO é mais complexo (electrões, protões, sazonalidade SAA).
- Não modela transientes rápidos (flashes, ESD, surto de comutação do EPS); foco é DC steady-state em open-circuit.

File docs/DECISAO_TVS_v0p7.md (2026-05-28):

# Decisão: popular `D1` com TVS na v0.7 — ICARUS

Data: 2026-05-28

> **⚠️ SUPERSEDED em v0.7 (2026-05-28, mais tarde no mesmo dia).** Mudança de topologia para paralelo (1S2P) — ver [VALIDACAO_TOPOLOGIA_PARALELO_v0p7.md](VALIDACAO_TOPOLOGIA_PARALELO_v0p7.md). Em paralelo, `Voc_max` cold ≈ 3.33 V, OVP não é necessária e o EPS já tem protecção integrada acima de 5.5 V. **`D1` foi removido por completo na v0.7**; o clamp TL431+MOSFET não é implementado. Este documento mantém-se como histórico do trade-off antes da mudança de topologia.

Estado: decisão de engenharia para a próxima revisão (v0.7). Aplica-se ao próximo PCB; v0.6 mantém-se como release de revisão interna sem alteração de BOM.

Relacionado: [ANALISE_TERMICA_VOC_v0p6.md](ANALISE_TERMICA_VOC_v0p6.md), [VALIDACAO_DATASHEETS_v0p6.md](VALIDACAO_DATASHEETS_v0p6.md).

## 1. Contexto

A `ANALISE_TERMICA_VOC_v0p6.md` quantificou que `Voc_2S` em pior caso (BOL, frio, circuito aberto, transiente pós-eclipse) chega a **6.18–6.26 V**, contra o limite de 5.5 V declarado para a entrada solar do EPS I por canal (Tab. 12 do manual).

A análise propôs três caminhos:
- A — clarificar com a EnduroSat se 5.5 V é operating ou absolute max
- B — popular `D1` com TVS clamp dimensionado < 5.5 V
- C — shunt regulator activo

## 2. Decisão

**Adoptar Opção B na v0.7.** `D1` deixa de ser DNP e passa a TVS bidireccional / unidireccional reverse-stand-off.

### Justificação

- Resposta da EnduroSat tipicamente demora semanas e atrasa o ciclo do projecto.
- Postura conservadora para flight hardware: **na ausência de confirmação documental contrária, tratar 5.5 V como destrutivo**. Custo do erro é a perda do EPS na primeira semana de missão.
- O custo do TVS é desprezável: 1 componente SMD, footprint `D_SOD-323` já reservado em `D1`, BOM cost < 1 €, área PCB < 5 mm².
- Mesmo que a EnduroSat venha mais tarde confirmar "operating max", o TVS não introduz risco — fica em alta impedância em condições nominais (`Vrwm > Vmp_2S = 4.74 V`).
- Estamos em BOL durante toda a primeira fase da missão, que é precisamente quando o risco existe. EOL severo (cell degradada) mitiga sozinho mas só ao fim de meses/anos.

## 3. Especificação do TVS

| Parâmetro | Requisito | Justificação |
|---|---|---|
| Topologia | Unidireccional | Painel só produz tensão positiva (PANEL_POS > PANEL_NEG); bidireccional desperdiça energia em reverse-leakage. |
| `Vrwm` (Reverse stand-off) | ≥ 4.8 V | Acima de `Vmp_2S = 4.74 V` para não conduzir em operação normal. |
| `Vbr_min` | ≥ 5.0 V | Margem ao Vmp para evitar leakage térmico. |
| `Vbr_max` | ≤ 5.4 V | Abaixo de 5.5 V para garantir clamp efectivo antes do limite EPS. |
| `Vc_max @ Ipp` | ≤ 6.0 V | Clamp em sobre-corrente (sem real risco aqui — `Isc_2S = 0.56 A` máx). Margem confortável vs limite EPS. |
| Pacote | SOD-323 (footprint actual de `D1`) | Sem alteração de layout. |
| Polaridade | Cátodo → PANEL_POS, Ânodo → PANEL_NEG | Standard reverse clamp. |
| Capacitância | < 200 pF | Irrelevante para DC; sem requisito RF. |
| Qualificação | Comercial-grade aceitável para v0.7 (revisão); upgrade para AEC-Q101 ou MIL-class antes de flight. | Risco mecânico/radiação é avaliado em revisão futura. |

### Candidatos concretos

| Part Number | `Vrwm` | `Vbr` | `Vc_max @ Ipp` | Pacote | Notas |
|---|---|---|---|---|---|
| **SMAJ5.0A** (Vishay) | 5.0 V | 6.40–7.07 V | 9.2 V | SMA | ❌ `Vbr` alto demais (6.4–7.0 V); só cortaria > 7 V, não protege. |
| **PESD5V0L1BA** (NXP) | 5.0 V | 6.0 V (typ) | 9.0 V | SOD-323 | ❌ Mesma razão; é ESD, não clamp DC. |
| **SMBJ5.0A** (Diodes Inc) | 5.0 V | 6.40–7.07 V | 9.2 V | SMB | ❌ Idem. |
| **TVS clamp 5.0 V de classe "low-clamping"** | — | — | — | — | Datasheet típico tem `Vbr` ~10–15 % acima de `Vrwm`; com `Vrwm = 5.0 V`, `Vbr` ≈ 5.5–5.75 V → ainda muito justo. |
| **Zener de precisão + MOSFET shunt** | — | 5.1 V Zener (`BZX84-C5V1`) | clamp activo a ~5.3 V | SOT-23 | ✅ Permite ajustar ponto de clamp; mais robusto. |

**Conclusão técnica**: o catálogo standard de TVS de 5.0 V não atinge a janela aperta de **[5.0, 5.4] V** que esta aplicação exige. Há um trade-off real:

- **Opção B1 (TVS simples, p.ex. SMBJ5.0A)**: protege mas só a partir de ~7 V → não cobre os 6.2 V do pior caso.
- **Opção B2 (Zener 5.1 V + N-MOSFET shunt)**: requer 2 componentes mas clamp efectivo a 5.3 V. Recomendado.
- **Opção B3 (TVS especial "low-clamping" — Nexperia PESD2CAN, ProTek SLVU2.8, etc.)**: pesquisar família com `Vbr ≤ 5.4 V` específica.

### Decisão de componente para v0.7

Adoptar **B2 com TL431** (precisão ±1 %, ver tabela detalhada na alternativa abaixo). Substituir `D1` actual (TVS DNP em SOD-323) por:

- **U1**: TL431AFTA em SOT-23 (referência precisão 2.495 V ±1 %)
- **Q1**: N-MOSFET BSS138 em SOT-23 (shunt de potência)
- **R1**: 10 kΩ 0603 ±1 % (divisor superior)
- **R2**: 8.87 kΩ 0603 ±1 % E96 (divisor inferior — fixa clamp em 5.30 V)
- **R3**: 100 Ω 0603 (limitação de corrente cátodo → gate)

Topologia: divisor `R1/R2` em `PANEL_POS` produz `Vref = 2.495 V` quando `V_PANEL = 5.30 V`. Acima disso, o cátodo do TL431 sink corrente, puxa gate de Q1 para terra → Q1 conduz e faz shunt do excesso entre `PANEL_POS` e `PANEL_NEG`.

Footprint changes vs v0.6:
- Remover `D1` (SOD-323 DNP).
- Adicionar `U1` (SOT-23), `Q1` (SOT-23), `R1`, `R2`, `R3` (3× 0603) ≈ 8 × 5 mm.
- Re-layout local em torno da posição actual de `D1` (120, 138) — a área disponível acomoda.

**Variante fallback (mais simples mas menos preciso)** — se houver pressão de área/BOM cost:
- **Z1**: Zener BZX84-C5V1 em SOT-23 (`Vz = 5.1 V`, tol. ±5 %)
- **Q1**: BSS138 SOT-23
- **R1**: 1 kΩ 0603
- Clamp em ≈ 5.1 V + Vgs(th) ≈ 5.9 V, com tolerância ±0.25 V do Zener. **Atenção**: janela apertada (5.0 V Vmp a 5.5 V EPS), tolerância pode comprometer o clamp. Só usar se TL431 for inviável.

**Alternativa single-part investigada e descartada (2026-05-28):**
- Bourns CDSOD323-T05L (SOD-323): `Vrwm = 5.0 V`, mas `Vbr_min = 6.0 V` → não clamp dentro do limite.
- TI TSDxx: variantes 3.6 V/4.5 V conduzem em MPPT (perde potência) ou 5.5 V/6.0 V não clamp.
- Nexperia PESDxL2BT: família ESD bidireccional, `Vbr` demasiado alto.
- Raiz do problema: TVS standard tem `Vbr ≈ 1.2 × Vrwm` mínimo. Para `Vrwm ≥ 4.8 V` (acima de `Vmp_2S = 4.74 V`), o `Vbr_min` cai para ≥ 5.8 V, fora da janela [5.0, 5.4 V] requerida.
- **Conclusão**: não existe TVS comercial single-part que cubra a janela. Clamp activo (Z1+Q1+R1, ou TL431+Q1+R1+R2) é a abordagem correcta.

**Variante recomendada — TL431 + MOSFET (preferível ao Zener+MOSFET):**

| Componente | Função | Referência sugerida |
|---|---|---|
| `U1` (TL431) | Referência precisão 2.495 V ±1 % | SOT-23, p.ex. Diodes Inc TL431AFTA |
| `R1` (10 kΩ) | Divisor superior, para `Vref = 2.495 V` corresponder a `Vclamp = 5.30 V` | 0603, ±1 % |
| `R2` (8.91 kΩ) | Divisor inferior (`R2 = R1 × Vref/(Vclamp−Vref) = 10k × 2.495/2.805`) | 0603, ±1 %, valor preferido 8.87 kΩ E96 |
| `Q1` | N-MOSFET small-signal a fazer shunt; `Vgs(th)` < 2 V | SOT-23, BSS138 ou DMN2300U |
| `R3` (100 Ω) | Limitação de corrente do cátodo do TL431 para a gate de Q1 | 0603 |

Vantagem vs Zener+MOSFET: precisão ±1 % do clamp em vez de ±5 % do Zener. Importante porque a janela [5.0, 5.4] V é apertada — tolerância larga do Zener (5.1 V ±5 % = 4.85–5.36 V) pode fechar a janela. TL431 fixa o clamp em 5.30 V ±0.05 V.

Espaço ocupado: 5 footprints SMD (TL431 SOT-23 + 3 resistors 0603 + 1 MOSFET SOT-23) ≈ 8 × 5 mm. Mais que o D1 actual SOD-323, mas área PCB tem espaço (canto de D1 actual + zona adjacente).

**AzurSpace / fornecedor espacial:** se preferes TVS qualificado, é praticamente impossível ter um na janela apertada — a recomendação dos fabricantes de células será tipicamente "use shunt regulator activo".

## 4. Trabalho concreto para v0.7

1. Re-spec `D1` como acima (Z1+Q1+R1 ou TVS low-clamping a confirmar).
2. Re-routing local em torno de `D1` para acomodar 3 footprints (se B2).
3. Re-validação do clamp em SPICE: simular `Voc_2S(T)` de −40 °C a +60 °C com clamp activo, confirmar `Vout_max < 5.5 V` em todas as condições.
4. Re-correr ERC + DRC parity.
5. Actualizar `VALIDACAO_DATASHEETS_v0p6.md` → `VALIDACAO_DATASHEETS_v0p7.md` reflectindo o clamp.
6. Manter este doc como rationale formal da decisão.

## 5. O que isto **não** resolve

- Não substitui análise térmica orbital própria (continua como acção do Porto Space térmico).
- Não substitui validação com a EnduroSat — se eles responderem mais tarde "5.5 V é operating max, sobressai sem dano até 7 V", o TVS fica como redundância barata; se confirmarem destrutivo, o nosso clamp já estava certo.
- Não cobre transientes ESD ou surtos do EPS (esses requerem TVS adicional na entrada digital do EPS, fora do escopo do painel).
- Continua a depender de qualificação espacial em revisões futuras.

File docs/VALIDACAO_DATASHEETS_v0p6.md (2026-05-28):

# Validação contra datasheets oficiais — ICARUS v0.6

Data: 2026-05-28

Estado: revisão interna pré-validação física. Não aprovado para fabrico final nem para voo.

## Fontes

- Célula: `TJ30SCA-4080V4.pdf` — Triple-Junction GaAs Solar CIC TJ3xSCA-4080 (coluna **Tipo 32**).
- EPS: `EPS_I_User_Manual.pdf` — EnduroSat EPS I & EPS I Plus, versão 7.12 (abril 2024), HW 1.7 / FW 16.78.

## Parâmetros confirmados (design vs datasheet)

| Parâmetro no design | Fonte oficial | Veredicto |
|---|---|---|
| Voc 2.70 V; Vmp 2.37 V; Jm 17.9 mA/cm²; área 30.18 cm² | Célula, coluna Tipo 32, AM0 25 °C | Match exato |
| dVoc/dT = −6.0 mV/°C por célula | Célula, Temperature Gradients (Voc, Tipo 32) | Match exato |
| EPS Vin máx = 5.5 V por canal | EPS Tab. 12 (Solar Panels Input, Voltage Max) | Match exato |
| EPS Iin máx = 1.8 A por canal | EPS Tab. 12 (Solar Panels Input, Current Max) | Match exato |
| Conector Molex 53398-0471, mates 51021-0400 | EPS Tab. 9 (conectores solares P1–P6) | Match exato |
| Pinout 1/2 = PV−, 3/4 = PV+ | EPS Tab. 8 | Match exato |

Margens de corrente/potência:

- Imp ≈ 0.54 A; Isc ≈ 0.56 A (Jsc 18.7 mA/cm² × 30.18 cm²) << 1.8 A → margem ampla de corrente.
- Pmp_2S ≈ 2.56 W; Vin típica do EPS = 4.66 V vs Vmp_2S = 4.74 V → ponto de operação bem casado.

## Actualização v0.7 — OVP integrada confirmada

A leitura da Tabela 12 e da Secção "Solar Panel Channels" do EPS I User Manual confirma:

- **"Over-voltage protection — engages above 5.5 V"** (citação directa). O limite 5.5 V é trigger de OVP integrada, não destrutivo absoluto.
- **`Voltage Min = 0 V`** na Tabela 12 — UVLO do boost ≈ `VF_blocking_diode + 0.5 V` ≈ 0.78 V.

Estas duas confirmações alteram o veredicto da Secção seguinte (a análise de risco quantificada continua tecnicamente correcta para 2S1P, mas a urgência é menor que era na v0.6). Mais importante: a v0.7 muda para 1S2P e o risco de sobretensão **desaparece** — ver [VALIDACAO_TOPOLOGIA_PARALELO_v0p7.md](VALIDACAO_TOPOLOGIA_PARALELO_v0p7.md).

## Risco de sobretensão (quantificado)

`Voc_2S` @ 25 °C BOL = 5.40 V, a apenas 0.10 V do máximo de 5.5 V. Coeficiente 2S = −12 mV/°C.

| Temp. da célula | `Voc_2S` (aberto, BOL) | vs 5.5 V |
|---:|---:|---|
| 16.7 °C | 5.50 V | no limite |
| 0 °C | 5.70 V | +0.20 V |
| −20 °C | 5.94 V | +0.44 V |
| −40 °C | 6.18 V | +0.68 V |

- Pior caso: **BOL + frio + circuito aberto** (início de missão, bateria cheia / sem carga).
- A radiação degrada `Voc` ao longo da vida (EOL/BOL Voc = 0.91–0.96 conforme fluência), pelo que o pior caso é mesmo no BOL.
- O manual do EPS I **não documenta proteção de sobretensão na entrada solar**. O díodo de bloqueio integrado (Vf 0.275–0.325 V) fica a jusante do pino de entrada e não limita `Voc`.
- Nota de extrapolação: o coeficiente térmico do datasheet é caracterizado para 20–80 °C; os valores a frio são extrapolação linear conservadora.
- Ação pendente: confirmar com a EnduroSat se 5.5 V é máximo absoluto/destrutivo; avaliar clamp/TVS dimensionado < 5.5 V (o `D1` atual é DNP).

## Dados novos a integrar no design

- **Díodo de bloqueio por canal no EPS** → o painel não precisa de díodo de bloqueio próprio.
- **Díodo bypass integrado na célula** (Vf < 1.0 V @ 2.5 A) → proteção de sombreamento já existe ao nível da célula; o `D1` (TVS) serve apenas como clamp/transiente.
- **Geometria mecânica da célula disponível no datasheet** (corpo 40.15 × 80.15 mm; tabs cotadas; altura com tabs 46.98 mm; CIC 270/300 µm; coverglass 120 µm; interconnector prata/Kovar, pull > 1.6 N; absorção ≤ 0.89) → permite validar/corrigir o footprint e alimentar a análise térmica que define a gama real de temperatura do painel.

## Impacto nas ações da v0.6

- Conector: P/N validado → **removido da lista de riscos**.
- Footprint da célula: passa de "preliminar sem referência" a "corrigível contra desenho cotado".
- README: removida a afirmação infundada de proteção de sobretensão do EPS na entrada solar.
- Sobretensão: **promovida a risco de design prioritário**, com decisão de mitigação pendente.

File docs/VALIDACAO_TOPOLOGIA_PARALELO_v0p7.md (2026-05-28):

# Validação da topologia paralela (1S2P) — ICARUS v0.7

Data: 2026-05-28

Estado: revisão interna pré-validação física. Não aprovado para fabrico final nem para voo.

Relacionado: [ANALISE_TERMICA_VOC_v0p6.md](ANALISE_TERMICA_VOC_v0p6.md), [VALIDACAO_DATASHEETS_v0p6.md](VALIDACAO_DATASHEETS_v0p6.md), [DECISAO_TVS_v0p7.md](DECISAO_TVS_v0p7.md).

## 1. Mudança de topologia

A v0.7 muda da topologia 2S1P (duas células em série) para **1S2P (duas células em paralelo)**. Decisão executada conforme orientação do líder de equipa do Porto Space (2026-05-28).

Justificação técnica (descobertas via leitura cruzada do EPS I User Manual, Tab. 12 e Secção "Solar Panel Channels"):

- O EPS I tem **Over-voltage protection** integrada que actua acima de 5.5 V (citação directa: "Over-voltage protection — engages above 5.5 V"). O limite 5.5 V **não é destrutivo absoluto** — é o trigger de OVP.
- O EPS I MPPT é **boost (step-up)**; UVLO ≈ `VF + 0.5 V` ≈ 0.78 V. Aceita tensões de entrada muito abaixo de 1 V.
- O `Voltage Min` para o canal solar na Tabela 12 é **0 V**.

Estas três descobertas tornam o paralelo eléctricamente atractivo e a anterior decisão de TVS na v0.6 ([DECISAO_TVS_v0p7.md](DECISAO_TVS_v0p7.md)) **obsoleta** — superseded pela nova topologia.

## 2. Parâmetros eléctricos comparados

| Parâmetro | 2S1P (v0.6) | 1S2P (v0.7) | Limite EPS | Veredicto |
|---|---|---|---|---|
| `Voc` por canal @ 25 °C BOL | 5.40 V | **2.70 V** | < 5.5 V (OVP) | ✅ |
| `Voc` cold extreme −80 °C BOL | 6.66 V | **3.33 V** | < 5.5 V (OVP) | ✅ OVP risk eliminado |
| `Vmp` @ 25 °C | 4.74 V | 2.37 V | > 0.78 V (UVLO) | ✅ |
| `Vin típica EPS` ref. | 4.66 V | 4.66 V | — | nota abaixo |
| `Isc` @ 25 °C | 0.56 A | 1.12 A | < 1.8 A | ✅ |
| `Imp` @ 25 °C | 0.54 A | 1.08 A | < 1.8 A | ✅ |
| `Pmp` @ 25 °C | 2.56 W | ≈ 2.65 W | — | ligeiramente maior |

Nota sobre `Vin típica` (4.66 V): é o ponto de operação típico **referenciado** pelo EPS, não um requisito. O EPS opera correctamente abaixo deste valor — usa o MPPT para encontrar o ponto óptimo dinamicamente. Operar a `Vmp_1S = 2.37 V` significa que o boost converter tem rácio mais alto (~1.7×), com pequena penalização de eficiência (boost típico é mais eficiente perto da unidade), mas funcionalmente correcto.

## 3. Topologia final (1S2P)

```
   ┌────────────── PANEL_POS ──────────────┐
   │                                        │
 SC1 (+, centro/verso, F.Cu)              SC2 (+, centro/verso, F.Cu)
 SC1 (−, tabs/frente, F.Cu)               SC2 (−, tabs/frente, F.Cu)
   │                                        │
   └────────────── PANEL_NEG ──────────────┘
```

Polaridade física da célula (TJ30SCA-4080V4, sem alteração de v0.6):
- Tabs da frente = NEG
- Centro/verso = POS

Mapa cell-pad → net:

| Célula | Pad físico | Pad # | Net |
|---|---|---:|---|
| SC1 | tabs (frente) | 1 | `PANEL_NEG` |
| SC1 | centro (verso) | 2 | `PANEL_POS` |
| SC2 | tabs (frente) | 1 | `PANEL_NEG` |
| SC2 | centro (verso) | 2 | `PANEL_POS` |

Note que ambas as células têm a mesma orientação eléctrica (tabs=NEG, centro=POS), simétrica entre si. Não há `SERIES_MID`.

## 4. Mudanças aplicadas

### 4.1 Schematic (`ICARUS_1U_Solar_Panel_PCB_v0p7.kicad_sch`)
- Renomeado de v0p6 → v0p7.
- Labels globais `SERIES_MID` (3 instâncias) substituídas: 2 viraram `PANEL_POS` e `PANEL_NEG` respectivamente; 1 foi removida com `TP2`.
- Símbolo `TP2` (test point SERIES_MID) eliminado.
- Símbolo `D1` (TVS DNP) eliminado por completo (ver Secção 5).
- Texto descritivo da topologia actualizado para 1S2P.
- Fios órfãos das labels antigas do `D1` removidos.

### 4.2 PCB (`ICARUS_1U_Solar_Panel_PCB_v0p7.kicad_pcb`)
- Renomeado de v0p6 → v0p7.
- Net `SERIES_MID` removida.
- Pads `SC1` centro (3×): net `SERIES_MID` → `PANEL_POS`.
- Pads `SC2` tabs (4×): net `SERIES_MID` → `PANEL_NEG`.
- Footprint `TP2` removido.
- Footprint `D1` removido.
- Texto fp_text actualizado (`SC1+ = PANEL_POS`, `SC2- = PANEL_NEG`).
- **J1 (Molex) movido de `F.Cu` para `B.Cu`** (parte inferior, conforme orientação do líder). Toda a referência F.* trocada para B.* (pads, silk, fab, courtyard, justificações de texto com `mirror`).
- Routing completamente refeito:
  - `PANEL_NEG`: bus F.Cu superior (tabs SC1) + bus F.Cu inferior (tabs SC2) + corredor B.Cu vertical à esquerda (x=70) ligando os dois + ligação B.Cu ao J1 (pin 1/2). Test pads TP1/TP4 ligam aos buses F.Cu via stubs.
  - `PANEL_POS`: bus F.Cu local em cada cell (y=84.425 e y=125.575) + corredor B.Cu vertical à direita (x=137) ligando os dois + ligação B.Cu ao J1 (pin 3/4). Test pads TP3/TP5 ligam aos buses F.Cu.

### 4.3 Pinout J1
- Mantido: P1/P2 = PV−, P3/P4 = PV+ (conforme Tabela 8 do EPS I User Manual e foto do conector real fornecida pelo líder).
- "Dois negativos e dois positivos" cumprido pela duplicação de pins na mesma polaridade (paralelo no conector — distribui corrente, reduz queda).

## 5. Destino do `D1` (TVS DNP)

`D1` foi **removido por completo** na v0.7. Justificação:
- Topologia paralela elimina o risco de Voc OVP (`Voc_2S = 6.18 V` em frio era o motivo da v0.6 considerar TVS; `Voc_1S = 3.33 V` em frio fica muito abaixo dos 5.5 V).
- EPS I tem OVP integrada no canal solar (manual confirma).
- Manter `D1` como DNP só ocupa área e BOM sem função real.
- `DECISAO_TVS_v0p7.md` fica como histórico — superseded.

## 6. Estado dos relatórios (KiCad 10.0 Windows)

- ERC: `reports/ERC_v0p7_kicad10_win.rpt`
  - 0 erros eléctricos.
  - 3 warnings: bibliotecas locais não activadas no contexto CLI (same as v0.6, mesmo waiver).

- DRC parity: `reports/DRC_v0p7_kicad10_win.rpt`
  - **0 erros**.
  - **0 desconectados**.
  - **0 paridade**.
  - 11 warnings: 3x `lib_footprint_issues` (lib CLI) + 8x `lib_footprint_mismatch` (TestPoint, MountingHole — embedded standard libs). Mesma natureza dos waivers da v0.6, agora com 2 menos (D1 e TP2 foram removidos).

- Plots: `reports/v0p7_top.svg`, `reports/v0p7_bottom.svg`, `reports/v0p7_fab.svg`.

## 7. Bloqueadores antes de fabrico (inalterados de v0.6)

- Footprint Molex 53398-0471 ainda preliminar até comparação com drawing oficial e conector real.
- Footprint da célula ainda preliminar até validação com célula real / desenho de montagem CIC (AzurSpace).
- Validação mecânica 1U (board outline, padrão de furos, encaixe das células).
- Continuidade pino-a-pino do harness real.
- Revisão por segunda pessoa (Porto Space hardware lead).

## 8. O que muda no risco de design

| Risco v0.6 | Estado v0.7 |
|---|---|
| Voc cold OVP > 5.5 V | **Eliminado** (Voc_1S max ≈ 3.33 V) |
| TVS clamp dimensionamento | **Não aplicável** (D1 removido) |
| Resposta EnduroSat sobre 5.5 V destrutivo | **Não bloqueante** (OVP integrada confirmada na Tab. 12) |
| Eficiência MPPT a 2.37 V | **Novo risco menor** — boost converter opera fora do ponto típico 4.66 V; espera-se ~5–10 % de perda de eficiência adicional vs 2S |
| Corrente de barramento (Isc 1.12 A vs 1.8 A limite) | Margem reduzida mas ainda 38 % de folga |

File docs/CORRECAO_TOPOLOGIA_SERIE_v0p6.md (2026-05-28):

# Correcao da topologia de serie das celulas - ICARUS v0.6

Data: 2026-05-28

> **⚠️ SUPERSEDED em v0.7 (2026-05-28).** A v0.7 mudou para topologia paralela (1S2P) — ver [VALIDACAO_TOPOLOGIA_PARALELO_v0p7.md](VALIDACAO_TOPOLOGIA_PARALELO_v0p7.md). A net `SERIES_MID` deixou de existir; ambas as células partilham `PANEL_POS` e `PANEL_NEG`. Este documento mantem-se como história da correccao anti-serie que aplicamos na v0.6.

Estado: correcao de erro critico de topologia. Pre-validacao fisica. Nao aprovado para fabrico nem voo.

## Problema

O PCB v0.6 ligava as duas celulas em **anti-serie** (saida ~ 0 V):
- Os dois contactos de verso (ambos POSITIVOS) estavam ambos ligados a `SERIES_MID`.
- O parity DRC nao apanha isto porque so compara `numero de pad <-> net`, nao qual o pad fisico.
- No SC2 os numeros de pad estavam trocados (verso=1/NEG, tabs=2/POS), invertendo a celula.

Polaridade fisica fixa da celula (TJ30SCA-4080): **tabs da frente = NEG; verso/centro = POS**.

## Topologia correta (2S)

`PANEL_NEG` -[SC1]- `SERIES_MID` -[SC2]- `PANEL_POS` (tensoes somam, ~5.4 V).

| Celula | Pad fisico | Polaridade | Pad # | Net |
|---|---|---|---:|---|
| SC1 | tabs (frente) | NEG | 1 | `PANEL_NEG` |
| SC1 | centro (verso) | POS | 2 | `SERIES_MID` |
| SC2 | tabs (frente) | NEG | 1 | `SERIES_MID` |
| SC2 | centro (verso) | POS | 2 | `PANEL_POS` |

Regra de verificacao: `SERIES_MID` tem de ligar o **verso(+) de uma celula** as **tabs(-) da outra** (um pad grande + um grupo de tabs), nunca dois pads do mesmo tipo.

## Alteracoes aplicadas

- Placement mantido (SC1 a 0 graus, SC2 a 180 graus, tabs para fora).
- SC2: numeracao de pads corrigida para a convencao da biblioteca (tabs=1, centro=2) e nets reatribuidas: tabs -> `SERIES_MID`, centro -> `PANEL_POS`.
- Contactos de verso (SC1 e SC2) movidos de `B.Cu` para `F.Cu` (face do componente).
- Esquematico mantido (ja estava fisicamente correto apos P0.1).
- Routing refeito em conformidade (`SERIES_MID` liga centro de SC1 as tabs inferiores de SC2; `PANEL_POS` liga o centro de SC2 a J1).

## Por confirmar antes de fabrico

- Esquema real de contacto de verso (bond condutivo vs wrap-around) e geometria das tabs: desenho de montagem CIC do fornecedor.
- Folga entre celulas suficiente para a interligacao real.
- DRC GUI/CLI limpo apos reroute (ver relatorios em `reports/`).

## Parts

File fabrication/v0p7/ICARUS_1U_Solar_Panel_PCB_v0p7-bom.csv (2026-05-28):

Reference | Value | Footprint | Quantity
J1 | Molex_53398-0471 | ICARUS_Connector:Molex_53398-0471_1x04_P1.25mm_PRELIMINARY | 1
SC1,SC2 | TJ3xSCA-4080_Type32 | ICARUS_Solar:TJ3xSCA_4080_CIC | 2

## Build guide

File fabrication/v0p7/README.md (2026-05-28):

# Fabrication outputs — ICARUS v0.7 (DRAFT)

Data: 2026-05-28

> **⚠️ DRAFT — NOT FOR FABRICATION.** Estes outputs estão gerados como preparação técnica, mas **não devem ser enviados a um fabricante** sem antes fechar os bloqueadores de validação externa em [`docs/VALIDACAO_EXTERNOS_v0p7.md`](../../docs/VALIDACAO_EXTERNOS_v0p7.md).

## Conteúdo

```
fabrication/v0p7/
├── README.md                                           ← este ficheiro
├── ICARUS_1U_Solar_Panel_PCB_v0p7-bom.csv              ← Bill of Materials
├── ICARUS_1U_Solar_Panel_PCB_v0p7-pos.csv              ← Pick-and-place
├── gerbers/
│   ├── ICARUS_1U_Solar_Panel_PCB_v0p7-F_Cu.gtl         ← Top copper
│   ├── ICARUS_1U_Solar_Panel_PCB_v0p7-B_Cu.gbl         ← Bottom copper
│   ├── ICARUS_1U_Solar_Panel_PCB_v0p7-F_Mask.gts       ← Top solder mask
│   ├── ICARUS_1U_Solar_Panel_PCB_v0p7-B_Mask.gbs       ← Bottom solder mask
│   ├── ICARUS_1U_Solar_Panel_PCB_v0p7-F_Silkscreen.gto ← Top silkscreen
│   ├── ICARUS_1U_Solar_Panel_PCB_v0p7-B_Silkscreen.gbo ← Bottom silkscreen
│   ├── ICARUS_1U_Solar_Panel_PCB_v0p7-F_Paste.gtp      ← Top stencil
│   ├── ICARUS_1U_Solar_Panel_PCB_v0p7-B_Paste.gbp      ← Bottom stencil
│   ├── ICARUS_1U_Solar_Panel_PCB_v0p7-F_Fab.gbr        ← Top fab (info)
│   ├── ICARUS_1U_Solar_Panel_PCB_v0p7-B_Fab.gbr        ← Bottom fab (info)
│   ├── ICARUS_1U_Solar_Panel_PCB_v0p7-Edge_Cuts.gm1    ← Board outline
│   └── ICARUS_1U_Solar_Panel_PCB_v0p7-job.gbrjob       ← Gerber job file
└── drill/
    ├── ICARUS_1U_Solar_Panel_PCB_v0p7.drl              ← Excellon drill
    └── ICARUS_1U_Solar_Panel_PCB_v0p7-drl_map.pdf      ← Drill map for review
```

## Especificações de fabrico

| Parâmetro | Valor |
|---|---|
| Tamanho da PCB | 95 × 95 mm |
| Layers | 2 (F.Cu + B.Cu) |
| Espessura nominal | 1.6 mm (a confirmar com fabricante e especificação Porto Space) |
| Material | FR-4 standard (a confirmar — TG mínimo recomendado 150 °C para espaço) |
| Cor da máscara de solda | Verde (default — alterar se preferência diferente) |
| Cor do silkscreen | Branco (sobre máscara verde) |
| Acabamento de superfície | ENIG recomendado para espaço (HASL aceitável para ground testing) |
| Min. track width | 0.5 mm (corredores B.Cu) |
| Min. clearance | 0.2 mm |
| Min. hole | 0.5 mm (via) / 3.2 mm (M3 mounting) |
| Via type | Padrão through-hole (0.6 mm diameter, 0.3 mm drill) |
| Drill origin | Absoluta (canto inferior esquerdo do board area) |
| Units | mm |

## Conteúdo do BOM

```
J1   Molex_53398-0471        × 1   ← conector solar para EPS
SC1  TJ3xSCA-4080_Type32     × 2   ← células solares
SC2  TJ3xSCA-4080_Type32           (mesmo P/N, montadas em paralelo)
```

Componentes NÃO em BOM (mas no PCB): mounting holes (H1-H4), test points (TP1, TP3, TP4, TP5). São footprints sem componente físico para comprar — fabricam-se com o PCB.

## Pick-and-place

3 componentes:
- J1 (Molex) em `bottom` (B.Cu) — montar primeiro?
- SC1 em `top`, rotação 0°
- SC2 em `top`, rotação 180° (tabs viradas para fora, conforme silk)

**Atenção**: as células CIC NÃO são pick-and-place automático. Requerem bonding manual (epoxy condutivo no centro/verso + soldadura nas tabs). O pos.csv tem-nas listadas para documentação mas a assembly real é manual.

## Bloqueadores antes de enviar a fabricante

Conforme [`docs/VALIDACAO_EXTERNOS_v0p7.md`](../../docs/VALIDACAO_EXTERNOS_v0p7.md):

- [ ] **Molex 53398-0471**: confirmar geometria dos pads contra drawing oficial ou conector físico → remover `_PRELIMINARY` do nome do footprint
- [ ] **Mecânica**: confirmar padrão M3 (actual 85.0 mm c/c) contra chassis Porto Space específico
- [ ] **CIC Assembly Drawing AzurSpace**: confirmar geometria tabs/contacto verso → potencialmente actualizar footprint da célula
- [ ] **Revisão por segunda pessoa** (P3 #30) — sign-off do líder hardware Porto Space
- [ ] **DRC GUI** corrido localmente (P1 #23) — opcional, CLI já corrido limpo

Adicionalmente:
- [ ] **Escolha do fabricante**: confirmar PCB capabilities (track/space/drill mínimos) vs nossos requisitos
- [ ] **Especificação completa do PCB**: stack-up, materiais, finish, marcação
- [ ] **Spec de acceptance**: testes eléctricos do fabricante, NCR procedure

## Como regenerar

Após qualquer mudança ao PCB:

```bash
# Gerbers
"/c/Program Files/KiCad/10.0/bin/kicad-cli.exe" pcb export gerbers \
    --output fabrication/v0p7/gerbers/ \
    --layers F.Cu,B.Cu,F.Mask,B.Mask,F.SilkS,B.SilkS,F.Paste,B.Paste,Edge.Cuts,F.Fab,B.Fab \
    hardware/ICARUS_1U_Solar_Panel_PCB_v0p7.kicad_pcb

# Drill
"/c/Program Files/KiCad/10.0/bin/kicad-cli.exe" pcb export drill \
    --output fabrication/v0p7/drill/ \
    --format excellon --drill-origin absolute --excellon-units mm \
    --excellon-zeros-format decimal --generate-map --map-format pdf \
    hardware/ICARUS_1U_Solar_Panel_PCB_v0p7.kicad_pcb

# Pick-and-place
"/c/Program Files/KiCad/10.0/bin/kicad-cli.exe" pcb export pos \
    --output fabrication/v0p7/ICARUS_1U_Solar_Panel_PCB_v0p7-pos.csv \
    --format csv --units mm --side both \
    hardware/ICARUS_1U_Solar_Panel_PCB_v0p7.kicad_pcb

# BOM
"/c/Program Files/KiCad/10.0/bin/kicad-cli.exe" sch export bom \
    --output fabrication/v0p7/ICARUS_1U_Solar_Panel_PCB_v0p7-bom.csv \
    --fields "Reference,Value,Footprint,Quantity" \
    --group-by "Value,Footprint" \
    hardware/ICARUS_1U_Solar_Panel_PCB_v0p7.kicad_sch
```

## Estado de geração

Gerado em 2026-05-28 a partir de `hardware/ICARUS_1U_Solar_Panel_PCB_v0p7.kicad_pcb` (commit `4aa482a` ou posterior). Re-gerar após cada commit que afecte o PCB ou schematic.

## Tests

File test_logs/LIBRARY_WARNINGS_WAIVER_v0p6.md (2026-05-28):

# Waiver tecnico de warnings ERC/DRC - ICARUS v0.6

Data: 2026-05-28 (revisto)

Estado: valido apenas para revisao interna pre-validacao fisica. Nao autoriza fabrico nem voo.

## Relatorios de referencia

- ERC CLI: `reports/ERC_v0p6_kicad10_win.rpt` (KiCad 10.0, Windows; 0 erros, 3 warnings de lib).
- DRC CLI: `reports/DRC_v0p6_kicad10_win.rpt` (KiCad 10.0, Windows; 0 erros, 13 warnings; 0 desconectados; 0 paridade).
- Corridas anteriores no macOS (`reports/ERC_v0p6.rpt`, `reports/DRC_v0p6.rpt`, `reports/DRC_v0p6_layout_only.rpt`) abortaram com exit -1 e foram removidas em 2026-05-28.
- DRC GUI: pendente ate ser executado manualmente no KiCad e guardado em `reports/DRC_GUI_v0p6.rpt`.

## Bibliotecas locais confirmadas no projeto

- `hardware/sym-lib-table` contem a biblioteca local `ICARUS` apontada para `${KIPRJMOD}/ICARUS.kicad_sym`.
- `hardware/fp-lib-table` contem `ICARUS_Solar` apontada para `${KIPRJMOD}/footprints/ICARUS_Solar.pretty`.
- `hardware/fp-lib-table` contem `ICARUS_Connector` apontada para `${KIPRJMOD}/footprints/ICARUS_Connector.pretty` (unificado em 2026-05-28).
- `hardware/ICARUS_1U_Solar_Panel_PCB_v0p6.kicad_pro` aponta para o esquematico `ICARUS_1U_Solar_Panel_PCB_v0p6.kicad_sch`.

## Warnings ERC restantes (3)

| Warning | Itens | Interpretacao | Estado |
|---|---|---|---|
| `footprint_link_issues` | `SC1`, `SC2` | O ERC CLI nao resolveu `ICARUS_Solar` no contexto usado, apesar de a tabela local existir. | Aceitavel para revisao interna; validar no KiCad GUI |
| `footprint_link_issues` | `J1` | O ERC CLI nao resolveu `ICARUS_Connector` no contexto usado, apesar de a tabela local existir. | Aceitavel para revisao interna; validar no KiCad GUI |

## Warnings DRC restantes (13)

### Grupo A: 3x `lib_footprint_issues` (mesma raiz que warnings ERC)

| Item | Footprint | Lib | Estado |
|---|---|---|---|
| `SC1` @ (105.000, 84.425) | `TJ3xSCA_4080_CIC` | `ICARUS_Solar` nao activada no contexto CLI | Limitacao do CLI; lib local existe |
| `SC2` @ (105.000, 125.575) | `TJ3xSCA_4080_CIC` | `ICARUS_Solar` nao activada no contexto CLI | Limitacao do CLI; lib local existe |
| `J1` @ (105.000, 150.000) | `Molex_53398-0471_1x04_P1.25mm_PRELIMINARY` | `ICARUS_Connector` nao activada no contexto CLI | Limitacao do CLI; lib local existe |

Raiz comum: o `kicad-cli` corre sem o contexto de utilizador que activa as bibliotecas locais do projeto (project-local lib tables). O KiCad GUI nao reporta estes warnings. Verificado abrindo o projeto no KiCad 10.0 Windows.

### Grupo B: 10x `lib_footprint_mismatch` (footprints standard embebidos)

| Item | Footprint | Lib | Razao do mismatch |
|---|---|---|---|
| `TP1`, `TP2`, `TP3` | `TestPoint_Pad_D2.0mm` | `TestPoint` | Copia embebida divergente da lib KiCad standard (campos cosmeticos: versao geradora, propriedades, tags) |
| `TP4`, `TP5` | `TestPoint_Pad_D2.5mm` | `TestPoint` | Idem |
| `D1` | `D_SOD-123` | `Diode_SMD` | Idem |
| `H1`, `H2`, `H3`, `H4` | `MountingHole_3.2mm_M3` | `MountingHole` | Idem |

Razao: ao guardar o projeto, KiCad copia o footprint para dentro do `.kicad_pcb`. A versao da lib instalada pode mudar de release para release. O mismatch nao indica erro electrico ou geometrico — apenas metadata divergente.

## Decisao para v0.6

- **Grupo A (3 warnings)**: limitacao do CLI; nao requer accao. Validacao final e feita no KiCad GUI durante a revisao manual.
- **Grupo B (10 warnings)**: dois caminhos validos:
  - (B1) Recomendado para fabrico: antes do CDR, abrir o projeto no KiCad GUI, "Update Footprints from Library" para `TestPoint`, `Diode_SMD`, `MountingHole`, e re-correr DRC. Espera-se que reduza a 0 warnings (mantendo geometria identica). 
  - (B2) Aceitavel para revisao interna: manter como esta, com este waiver. Os footprints embebidos sao auto-suficientes — o PCB pode ser fabricado com a versao actual sem depender da lib KiCad instalada na maquina de fabrico.
- v0.6 adopta (B2) para esta release interna. (B1) e accao de fecho antes do CDR.

## Actualizacao v0.7 (2026-05-28)

Na v0.7 o `D1` (TVS DNP) foi removido (paralelo torna desnecessario), eliminando 1 warning automaticamente. Adicionalmente, foi aplicada manualmente a opcao (B1) — os 4 footprints TestPoint (`TP1`, `TP3`, `TP4`, `TP5`) e os 4 MountingHole (`H1`-`H4`) foram sincronizados com as versoes da biblioteca standard do KiCad 10.0 (`C:\Program Files\KiCad\10.0\share\kicad\footprints\TestPoint.pretty`, `...\MountingHole.pretty`). Resultado em `reports/DRC_v0p7_kicad10_win.rpt`:

- **0 erros, 3 warnings**.
- Os 3 warnings restantes pertencem todos ao Grupo A (`lib_footprint_issues` para `ICARUS_Solar` em SC1/SC2 e `ICARUS_Connector` em J1) — limitacao do CLI sobre libs locais, mantida sob waiver.

Em v0.7 o waiver e portanto apenas para Grupo A. Grupo B esta resolvido.

## Limites deste waiver

- Estes warnings nao sao aprovacao de footprints.
- O footprint Molex continua preliminar ate comparacao com drawing oficial e conector real.
- O footprint da celula continua preliminar ate validacao com celula real/drawing.
- O DRC GUI completo com schematic parity continua obrigatorio antes de qualquer decisao de fabrico.
- A PCB continua nao `fabrication-ready` e nao `flight-ready`.

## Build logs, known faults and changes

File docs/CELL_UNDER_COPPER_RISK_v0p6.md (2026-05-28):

# Auditoria de cobre sob as celulas - ICARUS v0.6

Data: 2026-05-24

> **⚠️ Parcialmente SUPERSEDED em v0.7 (2026-05-28).** A topologia mudou para 1S2P paralelo e o J1 esta agora em B.Cu — ver [VALIDACAO_TOPOLOGIA_PARALELO_v0p7.md](VALIDACAO_TOPOLOGIA_PARALELO_v0p7.md). A net `SERIES_MID` listada abaixo nao existe na v0.7. A preocupacao geral (cobre sob celulas tem de ser consistente com a polaridade do contacto de verso) continua valida — em v0.7 todo o cobre sob ambas as celulas e' `PANEL_POS` (corredor B.Cu direito).

Estado: risco documentado para revisao interna. Nao aprovado para fabrico final nem para voo.

## Alteracao feita

- A rota principal `PANEL_NEG` em `B.Cu`, que antes passava pela lateral direita dentro da area nominal das celulas, foi desviada para o corredor exterior direito/inferior da PCB.
- As rotas dos test pads de `PANEL_NEG` e `PANEL_POS` foram desviadas pela margem esquerda/exterior para nao atravessarem a area nominal do corpo das celulas.

## Cobre que permanece sob a area nominal das celulas

| Net | Layer | Motivo | Estado |
|---|---|---|---|
| `SERIES_MID` | `B.Cu` | Interligacao dos pads de contacto da serie entre SC1 e SC2 | Pendente de validacao fisica |
| Pads de contacto das celulas | `F.Cu`/`B.Cu` conforme footprint | Contactos eletricos preliminares da celula | Pendente de drawing/celula real |

## Risco

- O footprint da celula ainda e preliminar.
- Nao esta validado se a face traseira/adesivo/isolamento da celula permite cobre mascarado sob a area ativa/corpo.
- Mesmo cobre coberto por solder mask pode ser insuficiente se houver abrasao, pressao mecanica, adesivo condutivo, tab desalinhada ou tolerancias de montagem.

## Validacao obrigatoria antes de fabrico

- Confirmar geometria real das tabs e contactos com drawing oficial ou celula real.
- Fazer dry-fit com celula real e material de fixacao previsto.
- Definir isolamento/adesivo compativel com a celula.
- Confirmar que nenhuma tab fica em contacto com cobre nao previsto.
- Rever se e necessario criar keepout absoluto de cobre sob a celula na proxima revisao.

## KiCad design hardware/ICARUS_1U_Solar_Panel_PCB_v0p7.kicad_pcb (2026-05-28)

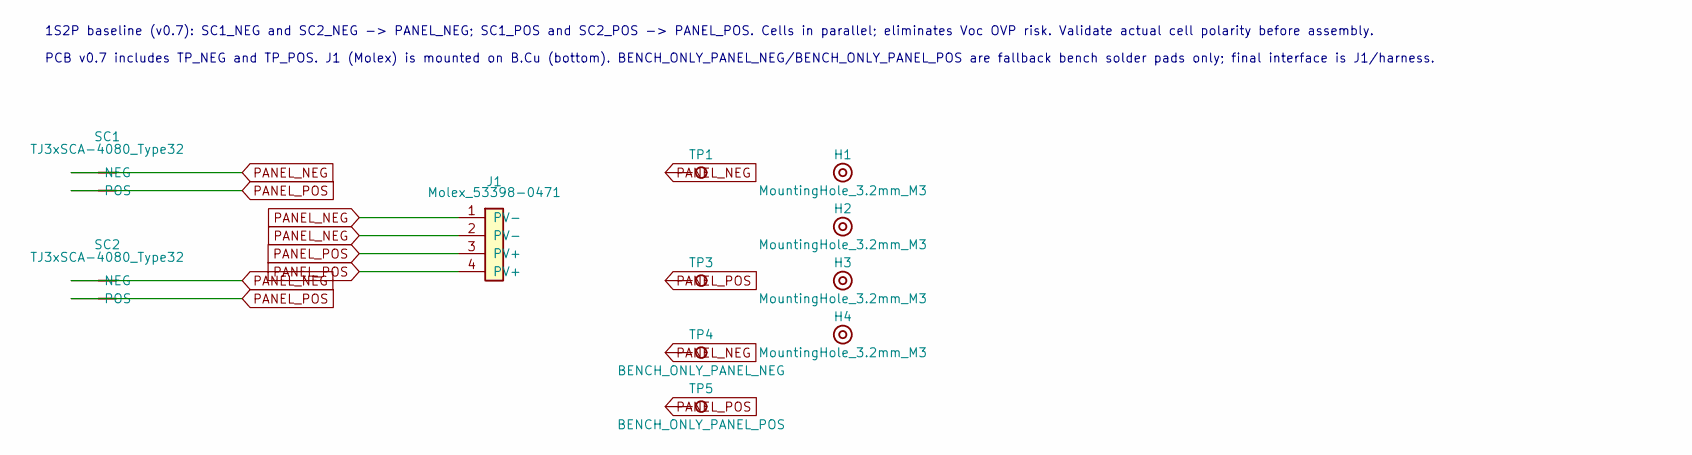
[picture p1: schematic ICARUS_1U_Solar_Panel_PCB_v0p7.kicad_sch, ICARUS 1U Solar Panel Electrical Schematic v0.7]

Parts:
H1, H2, H3, H4: MountingHole_3.2mm_M3
J1: Molex_53398-0471; Molex_53398-0471_1x04_P1.25mm_PRELIMINARY
SC1, SC2: TJ3xSCA-4080_Type32; TJ3xSCA_4080_CIC
TP1: PANEL_NEG; TestPoint_Pad_D2.0mm
TP3: PANEL_POS; TestPoint_Pad_D2.0mm
TP4: BENCH_ONLY_PANEL_NEG; TestPoint_Pad_D2.5mm
TP5: BENCH_ONLY_PANEL_POS; TestPoint_Pad_D2.5mm

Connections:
PANEL_NEG: J1.1 (PV-), J1.2 (PV-), SC1.1 (NEG), SC2.1 (NEG), TP1.1, TP4.1
PANEL_POS: J1.3 (PV+), J1.4 (PV+), SC1.2 (POS), SC2.2 (POS), TP3.1, TP5.1

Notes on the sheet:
1S2P baseline (v0.7): SC1_NEG and SC2_NEG -> PANEL_NEG; SC1_POS and SC2_POS -> PANEL_POS. Cells in parallel; eliminates Voc OVP risk. Validate actual cell polarity before assembly.
PCB v0.7 includes TP_NEG and TP_POS. J1 (Molex) is mounted on B.Cu (bottom). BENCH_ONLY_PANEL_NEG/BENCH_ONLY_PANEL_POS are fallback bench solder pads only; final interface is J1/harness.

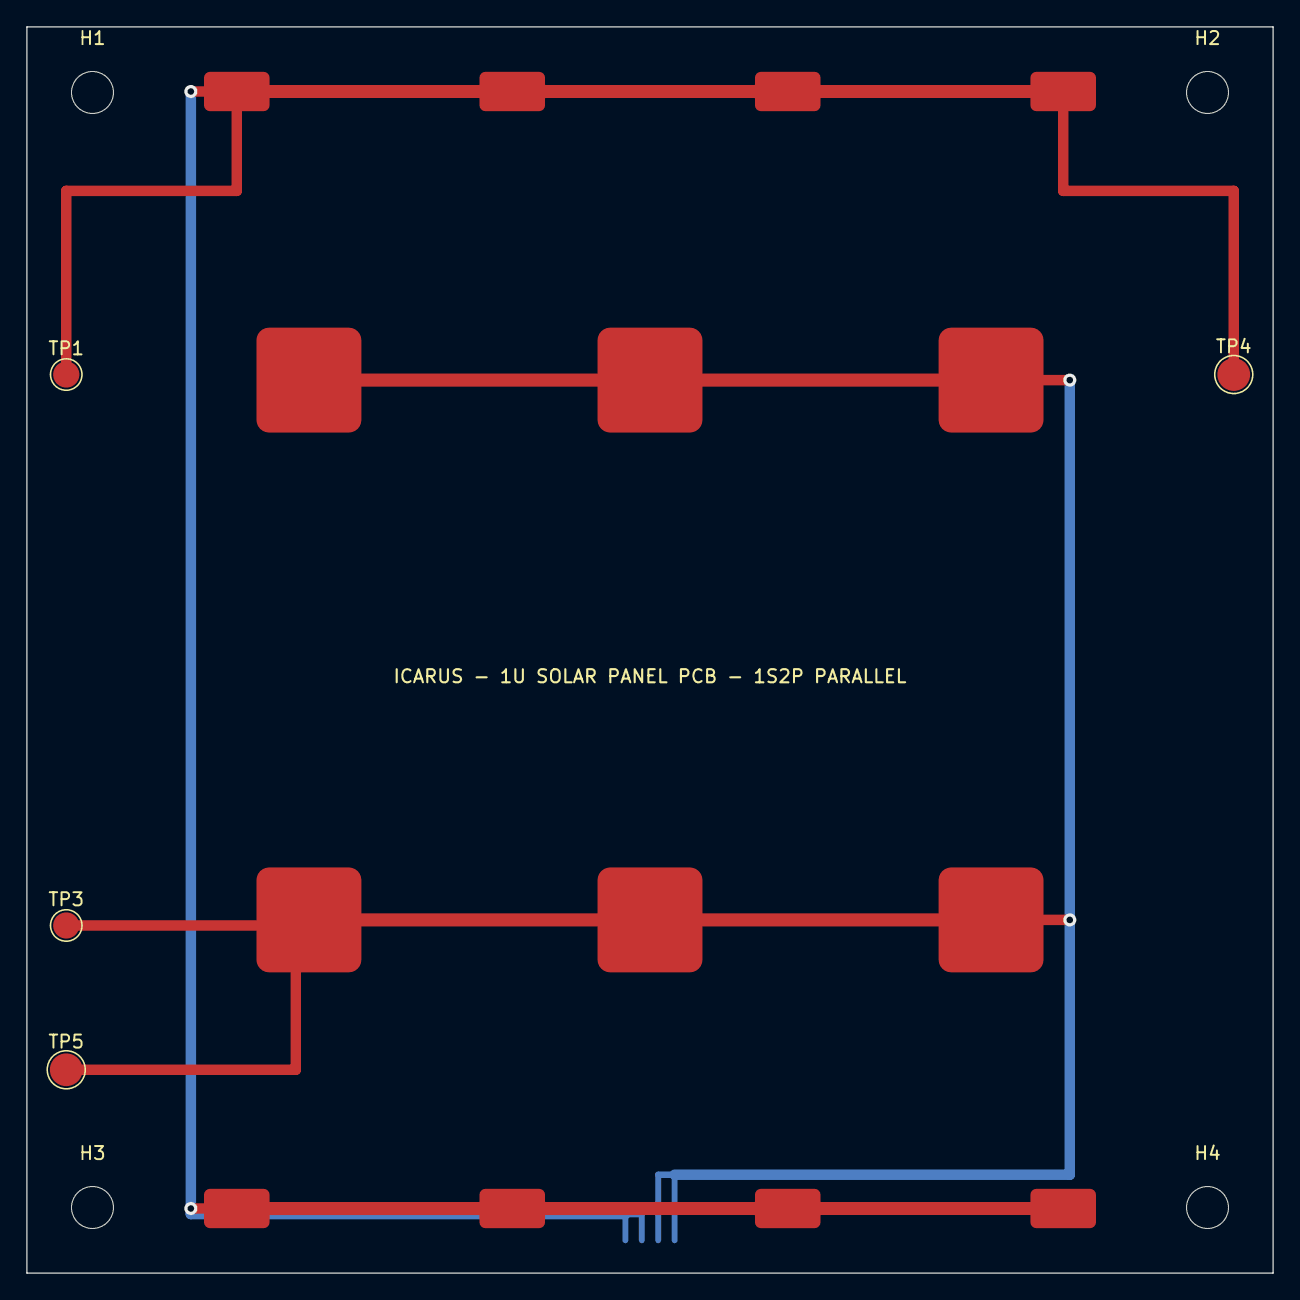
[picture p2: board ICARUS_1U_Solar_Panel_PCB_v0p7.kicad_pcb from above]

Board: 2 copper layers, 95.0 x 95.0 mm, 11 parts (1 on the bottom side), 2 nets.

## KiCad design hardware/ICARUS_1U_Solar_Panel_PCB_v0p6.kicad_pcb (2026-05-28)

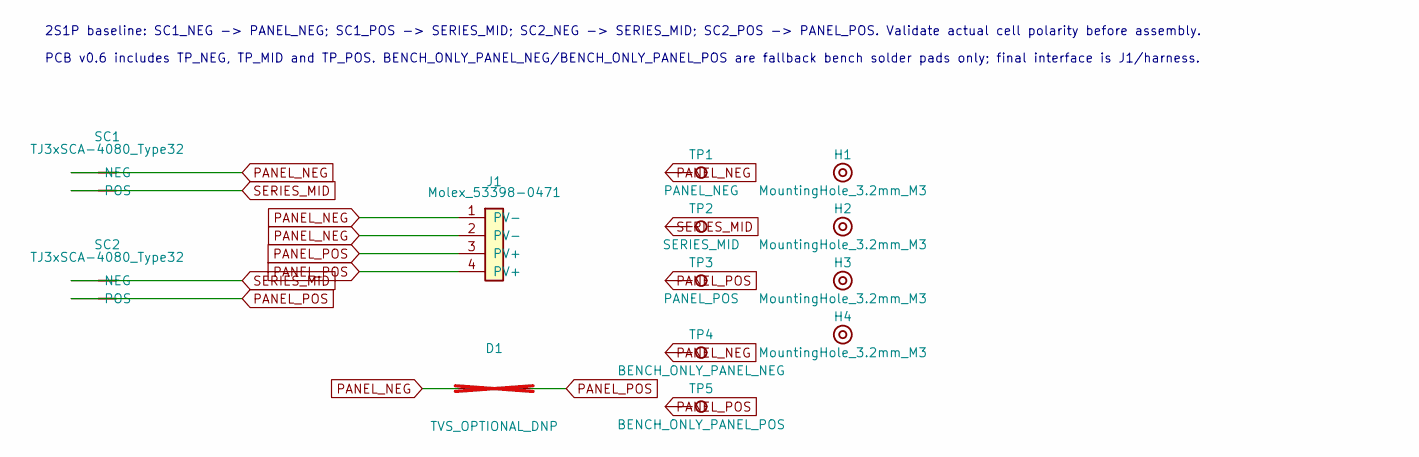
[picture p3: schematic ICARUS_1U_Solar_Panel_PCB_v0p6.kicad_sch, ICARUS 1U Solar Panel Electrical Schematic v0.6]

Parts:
D1: TVS_OPTIONAL_DNP; D_SOD-123; not fitted
H1, H2, H3, H4: MountingHole_3.2mm_M3
J1: Molex_53398-0471; Molex_53398-0471_1x04_P1.25mm_PRELIMINARY
SC1, SC2: TJ3xSCA-4080_Type32; TJ3xSCA_4080_CIC
TP1: PANEL_NEG; TestPoint_Pad_D2.0mm
TP2: SERIES_MID; TestPoint_Pad_D2.0mm
TP3: PANEL_POS; TestPoint_Pad_D2.0mm
TP4: BENCH_ONLY_PANEL_NEG; TestPoint_Pad_D2.5mm
TP5: BENCH_ONLY_PANEL_POS; TestPoint_Pad_D2.5mm

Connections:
PANEL_NEG: D1.1 (A), J1.1 (PV-), J1.2 (PV-), SC1.1 (NEG), TP1.1, TP4.1
PANEL_POS: D1.2 (K), J1.3 (PV+), J1.4 (PV+), SC2.2 (POS), TP3.1, TP5.1
SERIES_MID: SC1.2 (POS), SC2.1 (NEG), TP2.1

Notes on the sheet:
2S1P baseline: SC1_NEG -> PANEL_NEG; SC1_POS -> SERIES_MID; SC2_NEG -> SERIES_MID; SC2_POS -> PANEL_POS. Validate actual cell polarity before assembly.
PCB v0.6 includes TP_NEG, TP_MID and TP_POS. BENCH_ONLY_PANEL_NEG/BENCH_ONLY_PANEL_POS are fallback bench solder pads only; final interface is J1/harness.

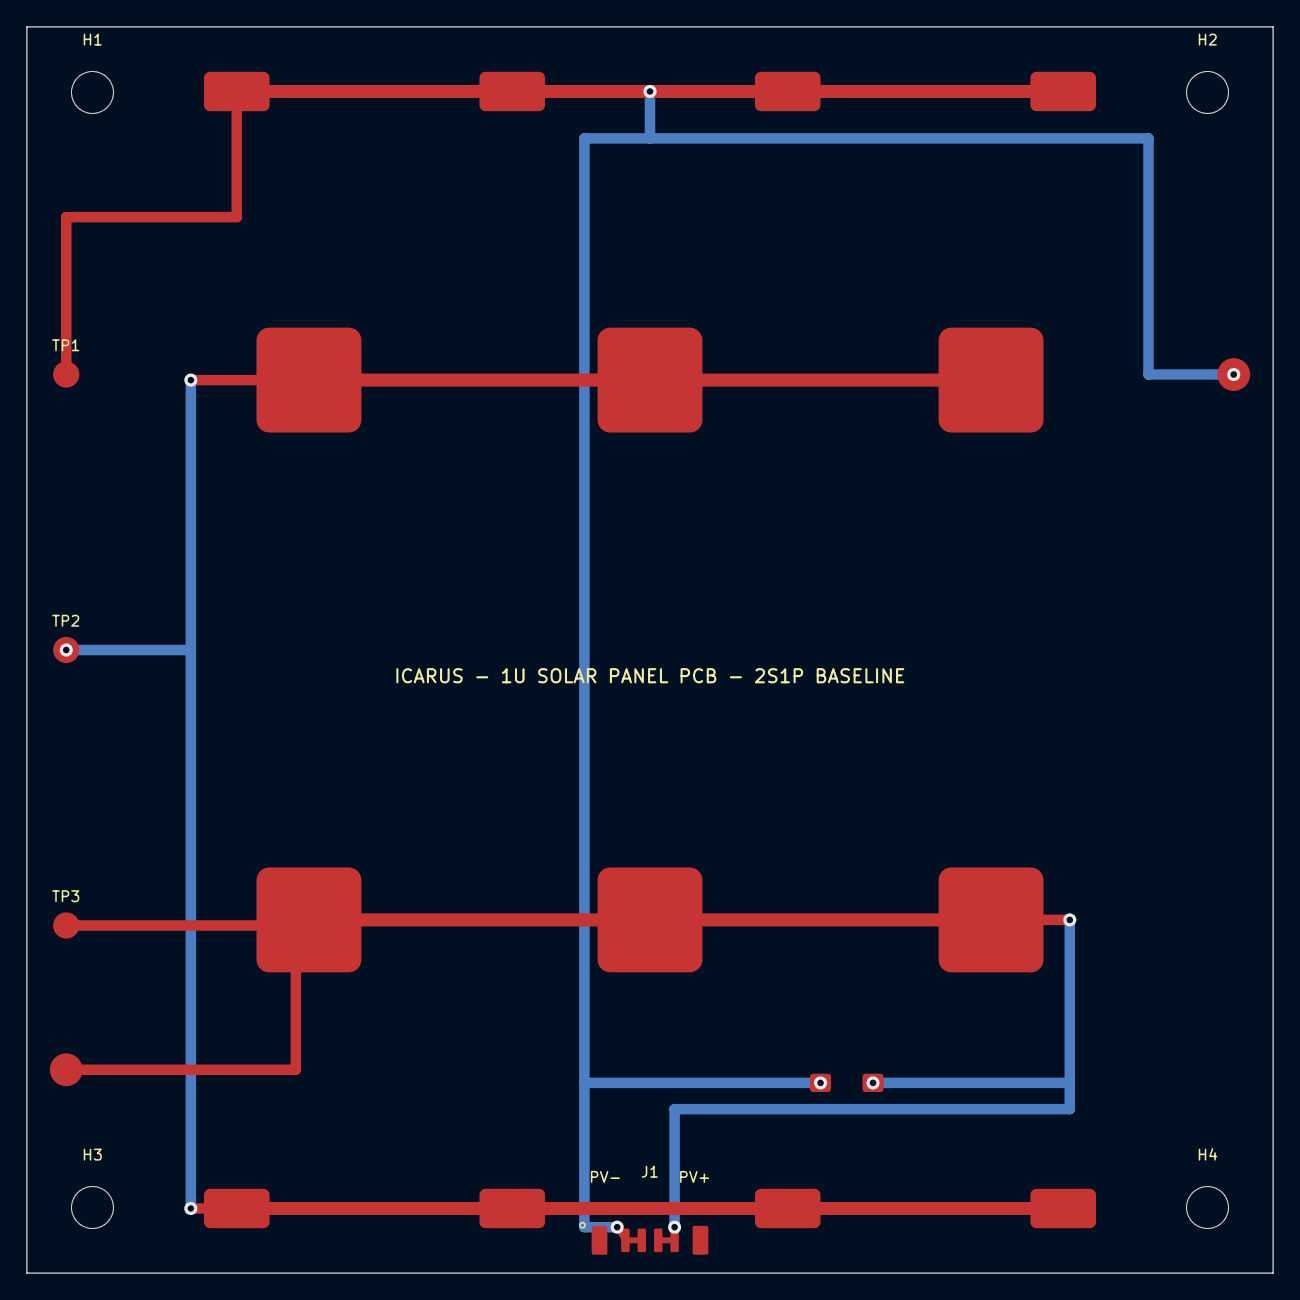
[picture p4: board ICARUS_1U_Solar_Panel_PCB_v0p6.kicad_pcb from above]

Board: 2 copper layers, 95.0 x 95.0 mm, 13 parts (0 on the bottom side), 3 nets.

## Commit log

2026-05-16 Initialize repository with ICARUS PCB design-review README
2026-05-16 Add ICARUS v0.2 KiCad PCB design-review board
    [ICARUS_1U_Solar_Panel_PCB_v0p2.kicad_pcb]
2026-05-16 Add ICARUS v0.2 KiCad project file
2026-05-16 Add review footprint for TJ3xSCA-4080 CIC solar cell
2026-05-16 Add panel-output connector placeholder footprint
2026-05-16 Add ICARUS PCB design review notes
2026-05-16 Adicionar ficheiro de teste
2026-05-16 Acrescentar secção de conteúdo
2026-05-16 Ajustar secção de conteúdo do README
2026-05-16 Adicionar notas de revisão técnica em português
2026-05-16 Traduzir notas técnicas para português de Portugal
2026-05-16 Rever footprint provisório do conector
2026-05-16 Rever footprint preliminar da célula
2026-05-23 Add v0.3 KiCad PCB with corrected EPS pinout and test pads
    [ICARUS_1U_Solar_Panel_PCB_v0p3.kicad_pcb]
2026-05-23 Add v0.4 KiCad schematic for ERC
    [ICARUS_1U_Solar_Panel_PCB_v0p4.kicad_sch]
2026-05-23 Add preliminary Molex 53398-0471 footprint for v0.4 validation
2026-05-23 Fix v0.4 schematic annotation by using numeric TVS reference
    [ICARUS_1U_Solar_Panel_PCB_v0p4.kicad_sch]
2026-05-28 Add ICARUS v0.6 internal-review revision; correct SC2 series polarity
    New KiCad project (sch/pcb/pro), local symbol library, fp/sym lib tables and ERC/DRC evidence for the v0.6 internal review. SC2 is wired in correct 2S1P series (SC2_NEG=SERIES_MID, SC2_POS=PANEL_POS), matching the PCB net assignment and the documented baseline. Removes superseded v0.2-v0.4 files and the placeholder connector footprint.
    Not fabrication-ready or flight-ready: DRC GUI with schematic parity is still pending (CLI aborted on macOS).
    [ICARUS_1U_Solar_Panel_PCB_v0p2.kicad_pcb, ICARUS_1U_Solar_Panel_PCB_v0p3.kicad_pcb, ICARUS_1U_Solar_Panel_PCB_v0p4.kicad_sch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]
2026-05-28 Add v0.6 docs and datasheets; validate design against datasheets; fix README
    Adds the v0.6 review docs (review actions, local validation, mechanical clearance, copper-under-cell risk) and the official datasheets (TJ30SCA-4080 cell, EnduroSat EPS I manual). New docs/VALIDACAO_DATASHEETS_v0p6.md cross-checks the design against the datasheets: cell electrical params, EPS 5.5V/1.8A input limits, Molex 53398-0471 connector and pinout all confirmed; cold-case Voc_2S overvoltage quantified. README corrected: removes the unsupported claim that the EPS provides solar-input overvoltage protection, syncs the repo contents list, and adds the cold Voc risk table. Removes superseded docs.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
2026-05-28 Run ERC/DRC on KiCad 10 (Windows): parity clean, 11 layout errors found
    Schematic-parity DRC now executes (the macOS CLI had aborted). Result: 0 parity problems (confirms the SC2 polarity fix) and 0 unconnected items, but 11 real layout errors: a PANEL_POS/PANEL_NEG short near J1 (2x), tracks routed through the M3 mounting holes (6x hole_clearance), and 3x clearance violations by J1. 13 warnings are local-library-not-enabled (waived) and standard-footprint library mismatches. Records evidence and updates the local validation doc.
2026-05-28 Move solar cell back-contact pad to component side (F.Cu) in cell footprint
    The cell is top-mounted on F.Cu (sun-facing), so its rear/positive contact (pad 2) must land on F.Cu, not B.Cu. The previous B.Cu assignment was physically incoherent (pad on the opposite side from the cell). Updates the library footprint and documents that the real contact scheme, tab geometry and polarity still require the vendor CIC assembly drawing. PCB instances (SC1/SC2) still carry B.Cu copies and must be updated during the layout/topology rework.
2026-05-28 Fix anti-series cell topology and reroute board to clean DRC
    The two cells were physically in anti-series (both back/+ contacts tied to SERIES_MID), which schematic-parity cannot detect. Corrected SC2 pad numbering and net assignment so the panel is a true 2S series (SERIES_MID = SC1 back + SC2 tabs), moved both back-contact pads to F.Cu, moved D1 (DNP) clear of the routing, and rebuilt all routing. KiCad 10 DRC with schematic parity: 0 errors, 0 unconnected, 0 shorts, 0 parity problems; remaining 13 are library-resolution warnings (waived). Adds CORRECAO_TOPOLOGIA_SERIE_v0p6.md and regenerates reports/plots.
    Cell back-contact scheme, tab geometry and D1 placement remain provisional pending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
    [ICARUS_1U_Solar_Panel_PCB_v0p6.kicad_pcb]
2026-05-28 Add .gitignore for KiCad local/generated files
2026-05-28 Add thermal Voc overvoltage analysis for v0.6
    docs/ANALISE_TERMICA_VOC_v0p6.md quantifies Voc_2S vs the EPS I 5.5 V
    input limit across temperature (BOL nom, BOL +1.5% tol, EOL leve, EOL
    severo), identifies the post-eclipse exposure transient as the critical
    regime, and lays out the EnduroSat-clarification + TVS-clamp decision
    tree.
2026-05-28 Repo hygiene: drop dead NC net, unify fp-lib-table, remove obsolete macOS reports
    - Drop unused (net 4 "NC") from PCB (was declared but referenced by no
    pad/track).
    - Point fp-lib-table entry for ICARUS_Connector at the unified
    hardware/footprints/ tree (matches ICARUS_Solar location).
    - Update bench-pad note in schematic to use the real net names
    (BENCH_ONLY_PANEL_NEG/POS) instead of the old short forms.
    - Delete the three .rpt files left from the aborted macOS DRC/ERC runs
    (DRC_v0p6.rpt, DRC_v0p6_layout_only.rpt, ERC_v0p6.rpt); current
    reports live in *_kicad10_win.rpt.
    DRC parity remains clean (0 errors / 0 unconnected / 0 parity issues;
    13 warnings = library-mismatch waived).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
    [ICARUS_1U_Solar_Panel_PCB_v0p6.kicad_pcb, ICARUS_1U_Solar_Panel_PCB_v0p6.kicad_sch]
2026-05-28 Refresh DRC/ERC reports, SVG plots and waivers after v0.6 cleanup
    - Re-run kicad-cli ERC + DRC (KiCad 10.0 Windows) after the dead-net
    removal and fp-lib-table unification: ERC 0 errors / 3 lib warnings,
    DRC 0 errors / 13 warnings / 0 parity / 0 unconnected.
    - Regenerate v0p6_top.svg, v0p6_bottom.svg, v0p6_fab.svg.
    - Update test_logs/LIBRARY_WARNINGS_WAIVER_v0p6.md: classify the 13 DRC
    warnings into Group A (3x lib_footprint_issues, CLI limitation) and
    Group B (10x lib_footprint_mismatch, embedded-vs-stdlib metadata),
    document the (B1) update-from-library path as the pre-CDR action and
    (B2) accept-as-is as the current v0.6 stance.
    - Sync docs/VALIDACAO_LOCAL_v0p6.md to the curren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
2026-05-28 Lock in TVS clamp decision for v0.7 (D1 populated, not DNP)
    Without waiting for EnduroSat clarification on whether 5.5 V is operating
    or absolute maximum, adopt the conservative flight-hardware default:
    treat 5.5 V as destructive and clamp before it.
    docs/DECISAO_TVS_v0p7.md documents:
    - Why we are not waiting for EnduroSat (cycle time + cost-of-error
    asymmetry).
    - Required clamp window: Vrwm >= 4.8 V, Vbr_max <= 5.4 V, Vc_max <= 6.0 V.
    - Why standard 5.0 V TVS (SMBJ5.0A class) misses the window (Vbr 6.4-7 V).
    - Selected approach: Zener BZX84-C5V1 + N-MOSFET shunt + bias R, replacing
    D1 SOD-323 DNP in v0.7.
    - Open follow-up: investigate low-clamping TVS families (Nexperia
    PESDXL2BT et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
2026-05-28 Promote TL431 active clamp as the v0.7 D1 solution
    Investigated single-part TVS in SOD-323 with Vrwm 4.8-5.0 V and Vbr_max
    <= 5.4 V (Bourns CDSOD323-T05L, TI TSD05, Nexperia PESDxL2BT): none
    fits. Standard TVS Vbr is ~1.2x Vrwm, so with Vmp_2S = 4.74 V forcing
    Vrwm >= 4.8 V, Vbr_min falls at >= 5.8 V — outside the EPS 5.5 V limit.
    Single-part TVS path is closed. Adopt TL431 active clamp:
    - TL431 SOT-23 reference (2.495 V +/-1 %)
    - BSS138 SOT-23 N-MOSFET shunt
    - 10 k + 8.87 k E96 1 % divider fixing clamp at 5.30 V (vs +/-5 % of
    the Zener variant — important in a 500 mV window)
    - 100 ohm cathode-to-gate current limit
    Zener+MOSFET (BZX84-C5V1) is documented as a fallback only; its
    +/-0.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
2026-05-28 Switch to parallel topology (1S2P) for v0.7
    Lead-team-driven topology change. Both cells now share PANEL_POS and
    PANEL_NEG nets (was 2S1P with intermediate SERIES_MID). J1 (Molex)
    moved from F.Cu to B.Cu (bottom side, as instructed). Re-routed for
    parallel: left B.Cu corridor (x=70) ties the two PANEL_NEG tab buses;
    right B.Cu corridor (x=137) ties the two PANEL_POS centre buses; both
    land on the bottom J1 pads. TP3/TP5 stay on F.Cu under SC2 (PANEL_POS
    on PANEL_POS) to avoid crossing the B.Cu PANEL_NEG corridor.
    Also removed: D1 (TVS DNP) and TP2 (SERIES_MID test pad), both obsolete
    in 1S2P. SERIES_MID net dropped from the PCB net table.
    Rename of v0p6.* -> v0p7.* across .kicad_sch / .kic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
    [ICARUS_1U_Solar_Panel_PCB_v0p7.kicad_pcb, ICARUS_1U_Solar_Panel_PCB_v0p7.kicad_sch]
2026-05-28 Document v0.7 parallel topology and supersede v0.6 OVP docs
    - Add VALIDACAO_TOPOLOGIA_PARALELO_v0p7.md: rationale (Tab. 12 OVP
    trigger at 5.5 V, UVLO 0.78 V, EPS step-up), 1S2P vs 2S1P
    parameter table, polarity map per cell pad, schematic + PCB
    change log, D1 removal rationale.
    - Mark ANALISE_TERMICA_VOC_v0p6.md and DECISAO_TVS_v0p7.md as
    SUPERSEDED — kept as engineering history.
    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
2026-05-28 Fix outdated board silkscreen labels for v0.7
    Two leftover cosmetic strings from the 2S1P baseline that were still
    showing in the KiCad GUI:
    - Board title: "2S1P BASELINE" -> "1S2P PARALLEL"
    - Test-point legend: "TP: PV- / MID / PV+" -> "TP: PV- / PV+" (TP2 was
    removed with the SERIES_MID net)
    DRC parity still clean (0 errors / 0 unconnected / 0 parity).
    [ICARUS_1U_Solar_Panel_PCB_v0p7.kicad_pcb]
2026-05-28 v0.7 cleanup: purge stale 2S1P / SERIES_MID / D1 / v0.6 references
    The previous v0.7 merge left several stale strings hardcoded inside
    files that the GUI still surfaced as if the board were still 2S1P.
    This pass catches them all:
    - PCB title block: v0.6 -> v0.7, "2S1P baseline" -> "1S2P parallel; J1 on B.Cu".
    - Schematic title block: same v0.6 -> v0.7 / 2S1P -> 1S2P update.
    - Schematic lib_symbols: drop the unused TVS_DNP_2Pin definition
    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
    [ICARUS_1U_Solar_Panel_PCB_v0p7.kicad_pcb, ICARUS_1U_Solar_Panel_PCB_v0p7.kicad_sch]
2026-05-28 Fix silk labels on the bottom side so J1 has readable markings
    The J1 connector moved to B.Cu in v0.7, but the PV-/PV+/EPS-pinout
    labels were still on F.SilkS / Cmts.User and the J1 footprint also
    carried a duplicate "P1/P2=PV-..." text on Cmts.User that rendered
    mirrored on top of the gr_text. From the assembly side the connector
    markings were invisible.
    Changes:
    - Move PV- and PV+ silk labels from F.SilkS to B.SilkS, swap their
    x positions so they land on the physically correct side when the
    board is viewed from the bottom (PV- ends up on the right next to
    pins 1/2, PV+ on the left next to pins 3/4).
    - Move "EPS I SOLAR: P1/P2=PV-..." and "VERIFY HARNESS CONTINUITY..."
    gr_texts fr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
    [ICARUS_1U_Solar_Panel_PCB_v0p7.kicad_pcb, ICARUS_1U_Solar_Panel_PCB_v0p7.kicad_sch]
2026-05-28 Sync TP and MountingHole footprints with KiCad 10 stdlib (zeros 10 warnings)
    Manually rewrote the 8 embedded footprints (TP1, TP3, TP4, TP5 +
    H1-H4) to match the structure of the standard KiCad 10.0 library
    versions in
    C:\Program Files\KiCad\10.0\share\kicad\footprints\TestPoint.pretty
    C:\Program Files\KiCad\10.0\share\kicad\footprints\MountingHole.pretty
    preserving the instance-specific bits (uuid, position, reference,
    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
    [ICARUS_1U_Solar_Panel_PCB_v0p7.kicad_pcb, ICARUS_1U_Solar_Panel_PCB_v0p7.kicad_sch]
2026-05-28 Validation against external sources: Molex, CubeSat CDS, AzurSpace
    Document P2 work I can do autonomously, organized into:
    1. Molex 53398-0471 — confirmed via Molex Product Specification
    PS-53398-001: part number, 1.25 mm pitch, 4 circuits SMT vertical,
    mates with 51021-0400 (matches EPS Tab. 9). Pad geometry is the
    open delta: current footprint pads are 0.65 x 1.8 vs typical 0.7
    x 1.6 from the SDK general PicoBlade pattern; needs official
    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
2026-05-28 P3 #27 thermal orbital analysis + P4 #31 fabrication outputs (DRAFT)
    P3 #27 — Orbital thermal analysis (1D radiation balance):
    - Hot case (OC, no MPPT extraction, BOL): T_cell ~= +62 deg C
    - Cold case (cold soak in eclipse): T_cell ~= -40 to -60 deg C
    - Eclipse-exit transient at T=-60 deg C BOL: Voc_1S(cold) ~= 3.21 V
    - All electrical parameters keep comfortable margin vs EPS limits
    in the 1S2P topology (Voc < 5.5 V OVP, Vmp > 0.78 V UVLO).
    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
    [ICARUS_1U_Solar_Panel_PCB_v0p7-B_Cu.gbl, ICARUS_1U_Solar_Panel_PCB_v0p7-B_Fab.gbr, ICARUS_1U_Solar_Panel_PCB_v0p7-B_Mask.gbs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]
2026-05-28 Add CLAUDE.md briefing for future sessions; expand .gitignore
    CLAUDE.md captures:
    - Project one-liner (ICARUS 1U solar panel PCB, Porto Space, EPS I)
    - v0.7 baseline: 1S2P parallel, J1 on B.Cu, D1 removed, TP2 removed
    - Validation status across electrical / Molex / mechanical / cell /
    harness / bench / second-person review / fabrication
    - The four key decisions that drove v0.7 (lead's parallel instruction,
    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
